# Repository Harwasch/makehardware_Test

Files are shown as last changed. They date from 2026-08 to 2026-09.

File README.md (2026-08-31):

# Ulysses LARS Charger

A 3 kW magnetic-resonant wireless charger that moves power from a surface
vessel's dock to a 48 V pack in an underwater vehicle, across a gap no
connector ever crosses.

Built with the [MakeHardware](https://github.com/Harwasch/MakeHardware) workflow.
This is **revision 2**; revision 1 is documented in
[`docs/design/v1-baseline.md`](docs/design/v1-baseline.md) and its source
material is preserved under `docs/reference/source/`.

<!-- PLAN:BEGIN -->
<!-- generated by plan_render.py — edit plan.yaml, not this block -->

Project plan

**0/28 chunks complete** · 16 sessions on the critical path · [editable version](docs/plan.drawio)

<!-- PLAN:END -->

## Where things stand

The four agreement stages — vision, plan, requirements, architecture — are
done. No design artefact exists yet, so `req-trace --gate` correctly reports
0% verified.

**There is no laboratory access.** Every number in this repository is an
analysis or simulation result, and the documents say so where it matters. Bench
verification is held as chunk `T2`, blocked, rather than deleted.

| Document | What it is |
|---|---|
| [`docs/design/vision.md`](docs/design/vision.md) | What we are building and the one decision it turns on |
| [`docs/design/v1-baseline.md`](docs/design/v1-baseline.md) | Revision 1 reviewed against its own datasheets — eleven findings, three blocking |
| [`docs/design/coil-model.md`](docs/design/coil-model.md) | Coil inductance, coupling and Q predicted from first principles |
| [`docs/design/in-band-comms.md`](docs/design/in-band-comms.md) | Data over the power coils, and why the tank bandwidth is the constraint |
| [`docs/design/environment.md`](docs/design/environment.md) | The marine ambient envelope and the 45 °C thermal budget it leaves |
| [`docs/design/adr-0002-tx-power-stage.md`](docs/design/adr-0002-tx-power-stage.md) | TX switch selection, and the two consequences worth knowing |
| [`docs/design/friction-log.md`](docs/design/friction-log.md) | What cost time, and which MakeHardware file should change |

## Reproducing the analysis

Every load-bearing number comes from a script, not a paragraph:

```bash
/opt/hw-py/bin/python sim/link-budget/link_budget.py     # resonant link matching, k*Q, loss budget
/opt/hw-py/bin/python sim/link-budget/comms_budget.py    # in-band data rate against tank bandwidth
/opt/hw-py/bin/python sim/link-budget/charge_policy.py   # C-rate policy and what it implies about the pack
cd sim/coil
/opt/hw-py/bin/python coil_model.py       # inductance, two methods, cross-checked
/opt/hw-py/bin/python coil_coupling.py    # coupling across the misalignment envelope
/opt/hw-py/bin/python coil_resistance.py  # AC resistance and quality factor
```

## The gates

```bash
hw-doctor                 # what the toolchain can actually do right now
/hw-status                # plan progress, what is ready to start, requirements coverage
plan-render --check       # cycles, dangling deps, done-on-unfinished
block-diagram --check     # architecture gate; exit 1 on an over-budget rail
./scripts/arch_diagram.py         # architecture sheets + power-budget.csv; fails
                                  #   on a wire over a box or a sheet too wide
./scripts/vision_md.py            # render concepts/ -> vision-gallery.md, HTML flattened
./scripts/md_flatten.py --check docs/review/*.md docs/design/*.md
req-trace --gate          # traceability gate; exit 1 while gaps remain
```

`req-trace --gate` exits 1 today and should. Do not make it pass by marking a
requirement `Verified` without evidence at the corners.

## Environment

This repo needs a Claude Code cloud environment built from
[MakeHardware's `env/`](https://github.com/Harwasch/MakeHardware/tree/HEAD/env) —
network access **Full**, the environment variables file, and the setup script.
Run `hw-doctor` first if anything behaves unexpectedly; the friction log records
two setup defects worth fixing before the next session.

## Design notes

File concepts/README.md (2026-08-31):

# concepts/

build123d models for the vision stage. Every dimension here is one the model
actually holds — these are geometry renders, not artistic impressions, so a
concept cannot show something unbuildable.

```bash
vision-md            # renders concepts/*.py and writes docs/design/vision-gallery.md
```

Run `vision-md`, not `vision-board` directly: it points the generated gallery at
`vision-gallery.md` so it stops overwriting the hand-written `vision.md`, and it
flattens the raw `<details>` blocks `vision-board` emits, which `review-artifact`
escapes into visible tags on the published review page.

| File | Concept |
|---|---|
| `_common.py` | shared geometry — coil pad, housing, enclosure, finned sink, dowel |
| `test_packaging.py` | the bench rig: pads on pins, gap set by shims |

**Scope is the electronics plus this one rig** (`VIS-013`). Integration — the
deck fixture, the vehicle mounting, the handling — is the mechanical team's, so
the rig is test equipment and not a fixture prototype. It is not marine, not
recoverable and not handled.

Two earlier generations of concept are withdrawn and deleted rather than kept as
dead files, because a stale concept is read as a live proposal:

* `dock_belly.py`, `dock_flank.py`, `dock_saddle.py` — docking arrangements.
  Settled at gate 1: belly dock, no actuator, charge on deck.
* `locate_cone_vee.py`, `locate_tapered_rails.py`, `locate_nest.py` — locating
  schemes. Withdrawn 2026-08-31 with the fixture; pins were taken from among
  them as the interface (`VIS-005`).

The coil pad is real — 102 × 203 mm at a 16 mm stack, from
`sim/coil/coil_rect.py`. The finned sink is sized against `MEC-009` and reports
its own area rather than asserting it; `sink_area_cm2()` is the number quoted.

Mass figures in the gallery are quoted at 1.4 g/cm³, which is `vision-board`'s
fixed assumption and wrong for an aluminium rig — `MATERIAL` sets the render
colour only. Multiply by 1.93 for aluminium, and remember the enclosures are
drawn as solid blocks.

No image backend is configured in this environment (`imagegen --list` reports no
keys), so styled or contextual imagery is not available. If the vision board
should look like a product rather than shaded CAD, that needs `FAL_KEY`,
`BFL_API_KEY` or `OPENAI_API_KEY` set in the environment.

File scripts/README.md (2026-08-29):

# scripts/

Vendored copies of the MakeHardware gate scripts, so the gates run in CI without
the plugin being installed.

| Script | What it does |
|---|---|
| `req_trace.py` | Traceability and coverage gate over `requirements/`. Exits 1 while gaps remain. |

These are **copies**, not the source of truth — the originals live in the
MakeHardware plugin and are what a local session runs via `req-trace`. If the
plugin's version changes, re-copy. The reason for vendoring rather than
installing the plugin in CI is that the plugin pulls a large toolchain (KiCad,
CalculiX, gmsh) that a documentation build has no use for.

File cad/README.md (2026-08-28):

# CAD

build123d models. Each file defines the geometry as code so a changed number is
a re-render, not a redraw.

Export STEP for the KiCad 3D view and STL for meshing. Link each model back to
the requirement it realises with a `File` relation in `requirements/`.

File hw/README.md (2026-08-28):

# Electrical design

| File | What it is |
|---|---|
| `block-diagram.yaml` | the architecture spec — **the only file here you hand-edit** |
| `block-diagram.drawio` | generated; open in draw.io to rearrange, positions are kept |
| `*.kicad_sch`, `*.kicad_pcb` | KiCad project — change these **only** through Konnect MCP tools |

The block diagram is settled before schematic capture. See the
`hw-block-diagram` skill; run `block-diagram --check` before calling the
architecture agreed.

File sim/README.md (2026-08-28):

# Simulation

SPICE decks and their results. A simulation only closes a requirement if it is
reproducible, so commit the deck alongside the numbers it produced.

Cross-check against closed form wherever one exists, and read the
`observations` field — ngspice prints `singular matrix` and then writes
plausible numbers anyway.

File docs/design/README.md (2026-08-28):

# Design documentation

How and why this system was built, written as the work happens.

* `adr-NNNN-<slug>.md` — decision records. One per decision that constrains
  anything downstream.
* `architecture.md` — the block-level picture and how the pieces divide.
* `interfaces.md` — board outline, connector pinouts, mounting, anything two
  disciplines have to agree on.
* `verification-report.md` — the output of the verification stage.
* `friction-log.md` — three-line entries written during the work, whenever a
  correction or an avoidable loop happens, each naming the MakeHardware file
  that should change. See the `hw-retro` skill.
* `retro.md` — the synthesis, written by `/hw-retro` at a milestone.

An ADR has: Status, Context, Decision, Consequences, Alternatives considered.
Write the Consequences honestly, the bad ones included — that section is what a
future session reads when the number has to move.

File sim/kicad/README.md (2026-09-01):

# sim/kicad — the DAB schematic, and how to run it

`dab-sim` is a full dual active bridge — eight switches, their body diodes, the
planar transformer and the customer-supplied 56 µH — drawn as a schematic and
simulated by ngspice. Everything in the power path is a drawn wire, so you can
trace it by eye; only the four gate nets `G1`–`G4` are labels.

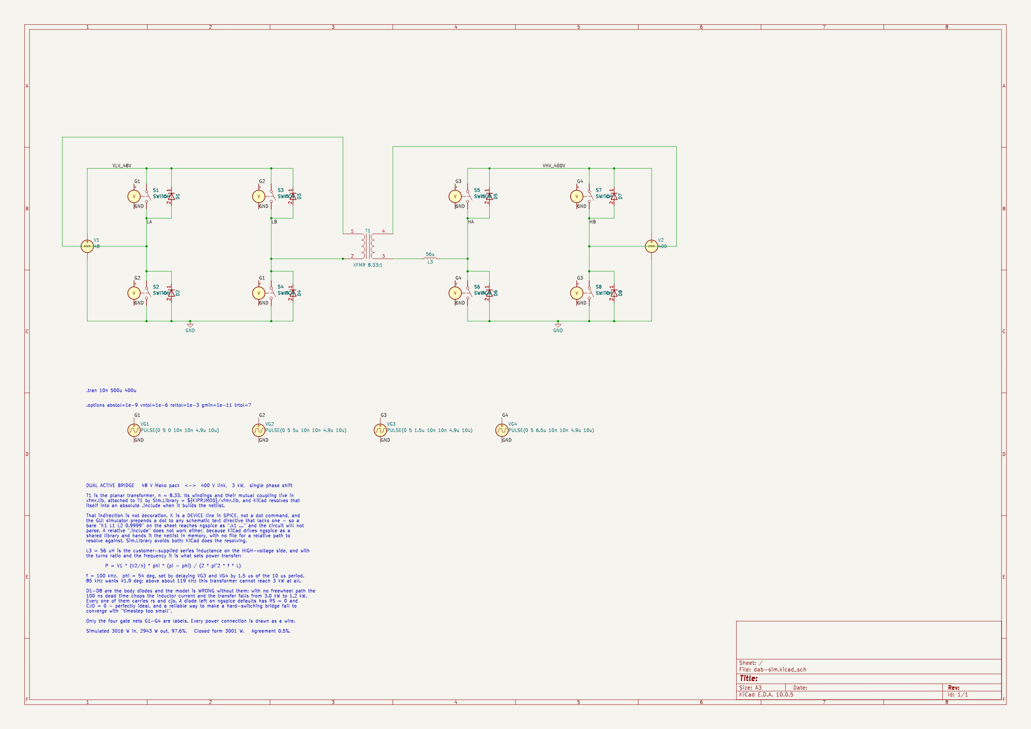
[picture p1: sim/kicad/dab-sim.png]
schematic


---

## Running it on your machine

### 1. What you need

**KiCad 8 or newer.** Built and verified here on **10.0.5**. The simulator is
ngspice, embedded in KiCad:

| Platform | ngspice |
|---|---|
| Windows | bundled with the KiCad installer — nothing to do |
| macOS | bundled with the KiCad `.dmg` — nothing to do |
| Linux | usually pulled in with the `kicad` package via `libngspice0`. If Simulator is greyed out, install `libngspice0` (Debian/Ubuntu) or `libngspice` (Fedora/Arch) and restart KiCad |

Nothing else. No SPICE models to fetch, no libraries to register — every symbol
is a stock KiCad one (`Simulation_SPICE`, `Device`, `power`) and the schematic
carries its own copy of each.

### 2. Open and run

```
git clone <this repo>
kicad sim/kicad/dab-sim.kicad_pro          # or File > Open Project
```

**The Simulator is in the Schematic Editor, not the Project Manager.** Open the
schematic first — double-click `dab-sim.kicad_sch` in the project tree, or press
the Schematic Editor button — and the **Inspect** menu appears. Simulator is
under it.

**Run will ask you for the simulation settings the first time. Give it:**

| Field | Value |
|---|---|
| Analysis | Transient |
| Time step | `10n` |
| Final time | `500u` |
| Time to start saving data | `400u` |

or, if the dialog offers a custom/direct command box, paste
`.tran 10n 500u 400u` into it. KiCad stores the command in the schematic, so it
only asks once.

**Why it asks, when the directive is right there on the sheet.** KiCad treats a
text item as *the simulation command* only when its **first line** starts with a
`.`. The directive block on this sheet reads

```
K1 L1 L2 0.9999          <- first line, does not start with a dot
.tran 10n 500u 400u
```

Both lines are exported into the netlist correctly — the coupling and the
analysis are genuinely there, which is why `run.sh` works — but the GUI does not
recognise the block as a simulation command, so it prompts.

### 3. The transformer coupling — already handled, but know why

Mutual coupling in SPICE is the `K` element, and **`K` is a device line, not a dot
command**. KiCad's GUI simulator prepends a `.` to any schematic text directive
that does not already start with one, so a bare `K1 L1 L2 0.9999` on the sheet
arrives at ngspice as `.k1 l1 l2 0.9999` and the circuit will not parse. Moving
it into a file and using a relative `.include` fails too: KiCad drives ngspice as
a **shared library** and hands it the netlist in memory, so there is no netlist
file for a relative path to resolve against.

Both are avoided here. The windings and their coupling live in `xfmr.lib` as a
subcircuit, attached to `T1` by

```
Sim.Library = ${KIPRJMOD}/xfmr.lib
Sim.Device  = SUBCKT
Sim.Name    = XFMR
```

**KiCad resolves that path itself** and writes an absolute, quoted `.include`
into the netlist. Absolute, so the shared library finds it; quoted, so a path
through a folder like `Wireless Charging Sim` is fine; and `${KIPRJMOD}` keeps it
portable, because the variable is resolved at netlist time on whatever machine
runs it. Nothing for you to edit.

### 4. Probing

With the Simulator window open, click a wire in the schematic to add it to the
plot; click a component pin to add its current. The nets worth probing are
already named, so they come up with sensible titles rather than `Net-_D1-A_`:

| Probe this | To see |
|---|---|
| `LA` and `LB` | the low-voltage bridge output — a 48 V square wave |
| `HA` and `HB` | the high-voltage bridge output — 400 V, phase shifted |
| current in **L3** | the tank current in your 56 µH. This is the waveform that matters: trapezoidal, and its slope is the voltage across the inductance |
| current in **V1** | input current from the 48 V pack, about 62.6 A average |
| current in **V2** | output current into the 400 V link, about 7.35 A average |
| `G1`–`G4` | the four gate drives, so you can see the phase shift |

For power rather than current, use the plot's **Add signal → expression** and
enter `v(/LA)*i(L1)` or similar.

### 5. Moving the operating point

Phase shift is the control input, and it is set by **when the high-voltage
bridge switches relative to the low-voltage one** — the delay field in `VG3`
and `VG4`. At 100 kHz the period is 10 µs, so 1 µs of delay is 36°.

| Want | Set VG3 delay | and VG4 delay |
|---|---|---|
| 54° — 3.0 kW, the shipped setting | `1.5u` | `6.5u` |
| 30° — less power, lowest current | `0.833u` | `5.833u` |
| 90° — maximum power, worst current | `2.5u` | `7.5u` |

Keep VG4 exactly 5 µs after VG3: they are the two halves of the same bridge.

To change frequency, every `10u` period and `4.9u` width in all four gate
sources has to move together, and the delays with them. **Above about 119 kHz
this transformer cannot reach 3 kW at any phase shift** — 56 µH is the limit.

### 6. Headless

Same schematic, same ngspice, no clicking:

```bash
./sim/kicad/run.sh              # measurements and a waveform plot
./sim/kicad/run.sh --no-plot    # measurements only, no matplotlib needed
```

It exports the netlist from the schematic with `kicad-cli`, swaps the `.tran`
for a `.control` block that also measures, runs it, and prints:

```
  input from the 48 V pack     3015.5 W   (62.82 A)
  output into the 400 V link   2942.9 W   (7.357 A)
  efficiency                     97.6 %
  tank current, HV side          9.53 A rms   10.34 A peak

  closed form for these values: 3001 W.  Deviation 0.5%.
```

Those are the numbers to expect from a clean run. If yours differ, something
changed. `PYTHON=/path/to/python ./run.sh` if the default interpreter has no
matplotlib.

---

## What the circuit is

`L1` / `L2` are the planar transformer, n = 8.33 so `L2 = L1 · n²`, coupled by
`K1` at 0.9999 — which makes `L3` the only leakage, deliberately, because `L3`
**is** the customer's 56 µH series inductance on the high-voltage side. That
inductance, the turns ratio and the frequency are what set power transfer:

```
P = V1 · (V2/n) · φ · (π − φ) / (2 · π² · f · L)
```

`D1`–`D8` are the body diodes, and **the model is wrong without them**: with no
freewheel path the 100 ns dead time chops the inductor current and the transfer
falls from 3.0 kW to 1.2 kW. That is measured, not asserted.

## Things that will bite you if you edit this sheet

**`Sim.*` properties must be on the symbol instance, not just the library.** A
symbol placed programmatically carries only Reference/Value/Footprint/Datasheet,
and the netlist then exports `S1 __S1` — no nodes, no model, and a run that
produces zero data rows. Every simulated part here carries `Sim.Device`,
`Sim.Pins` and `Sim.Params` as instance properties for that reason.

**Do not draw a rail straight across a row of switches.** The `SWITCH` symbol
puts its control pins at the same heights as its power pins, one grid column to
the left, so a horizontal rail through a switch row passes through every `C+`
pin and shorts the supply to the gate net. ngspice says `singular matrix: check
node vg2#branch` and returns nothing. The rails here run above and below the
switch rows with short stubs down to each pin — that is why the top rail sits at
y = 68.58 rather than on the pin row.

**Every diode carries `rs` and `cjo`, and that is not cosmetic.** A diode left
on ngspice's defaults has `RS = 0` and `CJO = 0` — a perfectly ideal switch with
no series resistance and no junction capacitance. In a hard-switching bridge
that is a reliable way to get `Timestep too small ... trouble with d4-instance`
and an aborted run. If you add a device to this sheet, give it real parameters.
The `.options` line beside the `.tran` loosens `abstol` from its 1 pA default,
which is meaningless in a circuit carrying 60 A.

**One ERC error is expected.** `power_pin_not_driven` on the GND symbols: KiCad
wants a `PWR_FLAG`, which matters for a board and not for a simulation. The
other ERC warnings you may see are library-table complaints that only appear if
`Simulation_SPICE`, `Device` or `power` are not in your global library table —
on a normal KiCad install they are.

## What this deck does not do

No switching loss, no ZVS, no parasitics, no thermal. The switches are ideal
with a 5 mΩ on-resistance and the diodes are generic. That is chunk `S2`, and it
needs real device models — the BSC190N15NS3 and IPB60R120C7 datasheets are still
listed as blocked in `docs/reference/manifest.yaml`.

The companion hand-written decks in `sim/link` and `sim/dab` cover the resonant
link and the phase-shift sweep. Findings from all of them are in
[`docs/design/sim-findings.md`](../../docs/design/sim-findings.md).

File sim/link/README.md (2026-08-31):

# sim/link, sim/dab

Two ngspice decks. Both are run by a Python driver that sweeps them and
cross-checks every point against closed form, because a simulator that agrees
with arithmetic is evidence and one that does not is a broken deck.

```bash
./sim/link/run_link.py     # resonant link  -> docs/design/sim-link.md
./sim/dab/run_dab.py       # DAB transformer -> docs/design/sim-dab.md
```

Read [`docs/design/sim-findings.md`](../../docs/design/sim-findings.md) for what
the numbers mean. The generated tables are numbers only.

**`link.cir`** is a faithful model of the white paper's resonant link: measured
coil values from page 6, bulk capacitance from page 5, 400 V bus, 85 kHz. Only
the compensation capacitance is computed, because the paper does not give it.

**`dab.cir`** is not a model of the white paper's DAB and cannot be. Page 8
names every semiconductor and none of the three parameters that set DAB power
transfer — turns ratio, leakage inductance, switching frequency. The deck runs
the inverse and solves for the leakage inductance 3 kW needs.

Neither deck carries switching loss, ZVS, dead time or parasitics; both use
ideal square-wave sources. That is chunk `S2`, and it is blocked on datasheets
that are not yet fetched — see `docs/reference/manifest.yaml`.

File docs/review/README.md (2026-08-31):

# Human review

An artefact the human has not seen is not a deliverable.

This directory is where agreement is recorded. Each review is a page the
human can open in a browser on github.com — because the agent works in a
cloud VM and that is the only surface the human actually has — plus a line in
`reviews.yaml` saying what they decided and what the artefacts looked like
when they decided it.

```
reviews.yaml       the sign-off ledger, with a digest per agreed artefact
<id>.md            one review packet per milestone or design stage
```

## The four milestones, at a minimum

| id | The artefact that renders on GitHub |
|---|---|
| `vision` | `docs/design/vision.md` and the renders beside it |
| `plan` | `docs/plan.md` (scope) and `docs/plan.svg` (dependency Gantt) |
| `requirements` | `docs/design/requirements-map.svg` |
| `arch` | `docs/design/arch-system.svg`, `arch-link.svg`, `arch-dab.svg`, `block-diagram.svg` |

Then one per large design stage — schematic, layout, enclosure, each
simulation campaign.

## The loop

```bash
review-gate open vision --title "..." --summary "..." \
    --artifact docs/design/vision.md --artifact docs/design/vision/ \
    --reference concepts/ \
    --question "Which concept, and why?"

#  ... ask the human directly with the printed github.com link, and wait ...

review-gate sign vision --approve --by <name> --note "<what they said>"
review-gate list                 # where every review stands
review-gate check --gate         # exit 1 while any milestone is open or stale
```

`--artifact` is what they are agreeing to: change one after sign-off and the
review goes **stale**, which fails the gate. `--reference` is a link to a
source file that legitimately churns — `plan.yaml`, a live `.kicad_sch` —
so the review does not break on every ordinary edit.

A chunk in `plan.yaml` that names a `review:` cannot be marked `done` until
that review is signed off. `plan-render --check` refuses it.

Full detail: the `hw-review` skill, and `hw-review/references/exports.md` for
how to turn a schematic, a board or a CAD model into something a browser can
open.

## Why the architecture milestone is `arch`, not `architecture`

`review-artifact`'s standard architecture phase is hardcoded to one figure,
`docs/design/block-diagram.svg`, and does not read the review's artefact list —
so a reviewer whose only access is the published page saw one diagram where
four were sent. It is replaced by a configured phase in
[`artifact.yaml`](artifact.yaml), which must use a different id because `hide`
suppresses a configured phase of the same id as well as the standard one. The
review binds to a phase by id, so the review is `arch` too, which keeps the
questions on the same tab as the drawings they are about.

`review-gate list` reports `architecture` as "never requested" for that reason.
That is expected, not a gap.

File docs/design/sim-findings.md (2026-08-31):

# What the simulations say

Two decks, both on ngspice-42, both cross-checked against closed form on every
point. Numbers live in the generated tables — [`sim-link.md`](sim-link.md) and
[`sim-dab.md`](sim-dab.md); this is what they mean.

Run them with `./sim/link/run_link.py` and `./sim/dab/run_dab.py`.

## What could be simulated, and what could not

The white paper supports a **faithful** simulation of the resonant link. It
gives measured coil values on page 6 — 12 µH, 0.8 Ω, Q of 12 — a 400 V bus, an
80–120 kHz band with 85 kHz nominal, and 11 µF of rectifier bulk capacitance on
page 5. Only the compensation capacitance is missing, and that follows from
resonance.

It does **not** support a simulation of the DAB. Page 8 names every
semiconductor — IPB60R120, BSC190N, UCC27741, ISO7740, ISO224, UCC1414,
UCC33420, TPSM560 — and none of the three parameters that set a DAB's power
transfer: transformer turns ratio, leakage inductance, switching frequency. A
deck built on assumed values would simulate our assumptions, not the design. So
`sim/dab/dab.cir` runs the inverse instead and solves for the transformer the
converter needs.

## F14 — the v1 coils cannot transfer 3 kW, by a factor of 6.75 in k

This is arithmetic before it is simulation. For series-series compensation
between two 400 V bridges,

    P = V1 * V2 / (omega * M)

so 3.0 kW at 85 kHz from a 400 V square wave (360 V rms fundamental) needs
**M = 80.9 µH**. Mutual inductance cannot exceed self-inductance, and the white
paper's coils are **12 µH**. Reaching 3 kW would need k = 6.75, where k ≤ 1 by
definition. The coils are roughly an order of magnitude too small.

The simulation shows what that looks like in practice. Driven at resonance at
400 V, the v1 tank draws **403 A rms** and puts **4.07 kV** across the
compensation capacitor. The LMG2610 the white paper selects is rated 6.4 A.
Coil dissipation at that current is 403² × 0.8 ≈ **130 kW** in a pad that has
to shed its heat by conduction alone.

The v1 link is therefore not a design that underperforms; it is one that cannot
be operated at its stated bus voltage at resonance at all. Which is consistent
with what the white paper reports from the bench: a resonance tracker that
hunts, and a system characterised at far lower power.

**Held fixed:** 85 kHz drive, 400 V bus, series-series compensation, the coil
as built. **Not varied:** operating frequency far off resonance, a lower bus
voltage, parallel compensation. Any of those makes the v1 hardware *do*
something — none of them makes it deliver 3 kW, because M is the binding limit
and none of them changes M.

## F15 — the white paper's Q of 12 does not hold at the stated frequency

Q = ωL/R with the paper's own L and R gives **8.0 at 85 kHz**, not 12. Q reaches
12 at about 127 kHz, above the top of the 80–120 kHz band the paper specifies.
Nothing downstream depends on this, but a Q quoted without its frequency is how
a coupling budget goes wrong, and `MEC-001` is written as k·Q for that reason.

## F16 — the corrected coil works, and puts 471–622 V on the rectifier

The ADR-0001 design point — 24 turns, 0.25 mm trace, 4 oz, 16 transposed
layers, from `sim/coil/coil_rect.py`, not from memory — gives L = 220 µH,
R_ac = 0.673 Ω and k of 0.433 to 0.572 across the `SYS-006` envelope. Simulated,
it moves 2.1–2.8 kW at **4–8 A** of tank current: three orders of magnitude off
the v1 currents, and inside every device rating.

But the operating point is not where the architecture assumes. With a passive
rectifier, output voltage is set by the load, and delivering 3 kW puts the
rectifier at **471 V at the worst corner, 566 V nominal and 622 V at minimum
gap** — not the 400 V of the `HVDC` rail in `hw/block-diagram.yaml`. Two
consequences, and both are open:

* The rail is misspecified. `HVDC` is 400 V in the block diagram and the real
  figure is roughly 470–620 V, which changes the device voltage class on the
  vehicle DAB's high-voltage bridge.
* It **varies by 32% across the docking envelope** at constant power. The
  downstream DAB has to absorb that, which is a control requirement nobody has
  written yet.

An actively rectified receiver would decouple power from output voltage and
remove both. That is an architecture decision, not a simulation result, and it
belongs to the human.

## F17 — the vehicle DAB's loss budget does not close, and ELE-003's rationale was wrong

Solving for the transformer at 3 kW, 48 V to 400 V:

| φ | L_lk referred to LV | referred to HV | tank rms |
|---:|---:|---:|---:|
| 30° | 0.53 µH | 37 µH | 70.7 A |
| 90° | 0.96 µH | 67 µH | 102.3 A |

at 100 kHz; at 150 kHz the inductances scale by 2/3 and the currents do not
move. Small phase shift is clearly right — same power, 30% less current — and
0.53 µH referred to the low-voltage side is the number the planar transformer
should be specified to.

The conduction loss that follows is the problem. Each switch position conducts
for half the cycle, so a device carries I_rms/(√2·N) with N in parallel, and the
whole low-voltage bridge costs 2·I_rms²·R_ds/N:

* **two devices per branch**, as the white paper specifies — **152 W** at the
  best phase shift
* **four devices per branch**, as `ELE-003` specifies — **76 W**

`ELE-003` budgets **100 W for the entire vehicle-side converter**, rectified DC
to pack terminals. Four per branch spends 76% of that on low-voltage conduction
alone, before the high-voltage bridge, the transformer, or any switching loss.
Two per branch exceeds the whole budget by 52%.

**`ELE-003`'s rationale was wrong and has been corrected.** It claimed 74 W for
two devices and 37 W for four; both were understated about twofold because the
half-cycle factor was dropped. The conclusion it drove — four devices per branch
rather than two — survives and is strengthened. The budget it asserts does not.

`R_ds(on)` here is the 19 mΩ family figure for BSC190N15NS3 scaled 1.6× for
temperature, and it is **not confirmed against a fetched datasheet**. It is
recorded as blocked in `docs/reference/manifest.yaml`. The 100 W budget is the
requirement's, so the gap is real either way, but its size moves with this
number and it should be confirmed before `ELE-003` is re-budgeted.

## What these decks do not cover

Deliberately, and they should not be read as if they did:

* **No switching loss, no ZVS, no dead time.** Both decks use ideal square-wave
  sources. That is the right reduction for a power-transfer question and the
  wrong one for a thermal answer. Chunk `S2` needs real device models, and
  those need datasheets that are not yet fetched.
* **No EMC, no parasitics.** The white paper is explicit that GaN slew rate and
  loop inductance are the hard part of the TX layout; nothing here models that.
* **The rectifier is a generic fast diode.** The paper names MURSDA860 but gives
  no ratings, and a 400 V — let alone 620 V — rectifier is a voltage-class
  question. Recorded as blocked in the manifest.
* **The DAB deck is a power-transfer core**, two square waves across the
  leakage inductance. It says nothing about the magnetising current, the
  transformer's loss, or bridge behaviour at light load.

## F18 — the M = 80.9 µH target assumed an ACTIVE receiver, and the deck used a passive one

Raised by the customer, and they were right to ask. To be clear first: **M is
about the wireless TX-to-RX link, not the DAB.** The DAB has its own series
inductance, and it is a different number in a different place.

The muddle is real, though, and it is mine. Two formulas describe an SS-compensated
link and they are not interchangeable:

* both ends actively switched — `P = V1 * V2 / (omega * M)`. This is what gives
  M = 80.9 uH for 3 kW at 85 kHz between two 400 V bridges, and it is what
  ``MEC-002`` was written from.
* a passive diode rectifier on the receiver — `P = V1^2 * R_ac / (omega * M)^2`,
  where the output voltage is set by the load, not by a bridge.

`sim/link/link.cir` models a **passive** rectifier, because that is what
``U10`` is in the block diagram. So the 80.9 uH figure and the simulation
describe two different receivers, and F16's 471-622 V output is exactly the
symptom of that mismatch.

This sharpens the F16 decision rather than replacing it. **Active rectification
restores M = 80.9 uH as the design target AND regulates the output back to
400 V — it fixes both problems at once.** A passive rectifier means ``MEC-002``
has to be rewritten, because M stops being the governing quantity.

## F19 — the coil is designed for the wrong M, and 24 turns is 20

Following F18 through to the active-rectifier case exposes a second-order error
in ``ADR-0001``. Power transfer is INVERSELY proportional to omega times M, so
too much coupling limits power just as surely as too little:

| turns | L | M | k·Q | P max at 400 V, 85 kHz |
|---:|---:|---:|---:|---:|
| 24 (ADR-0001) | 220 µH | 114.6 µH | 90.9 | **2.12 kW** |
| 22 | 192 µH | 97.9 µH | 84.2 | 2.48 kW |
| **20** | **166 µH** | **82.2 µH** | **77.3** | **2.95 kW** |
| 18 | 140 µH | 67.7 µH | 70.3 | 3.59 kW |

``ADR-0001`` picked 24 turns by maximising k·Q, which is the EFFICIENCY figure,
and never checked M against the POWER requirement. At 24 turns the link tops out
at 2.12 kW — it cannot reach 3 kW at 400 V however well it is driven.

**20 turns gives M = 82.2 µH against the 80.9 µH ``MEC-002`` asks for, reaches
2.95 kW, and still carries k·Q of 77.3 against the 49 ``MEC-001`` requires.**
The efficiency margin was never the binding constraint; it just looked like it
because it was the only thing being optimised.

``ADR-0001`` and ``MEC-002`` both need revising to 20 turns, and that is M2's
work. It does not change the coil technology decision — a transposed
multi-layer etched PCB coil still passes — only the turn count.

## F20 — the 56 µH lands inside the range the DAB deck solved for

The customer supplied it: there is a **56 µH inductor in series with the DAB's
PCB-coil transformer**. `sim/dab/run_dab.py` had solved for 37-67 µH referred to
the high-voltage side, so the real part sits squarely inside the predicted band,
which is a useful check on the deck.

It must be the high-voltage side: referred to the low-voltage side, 56 µH would
cap the converter at 51 W. Referred properly it is 0.806 µH, and it pins the
operating point that was previously open:

| f | phase shift for 3.0 kW |
|---:|---:|
| 85 kHz | 41.9° |
| 100 kHz | 54.0° |
| 150 kHz | cannot reach 3 kW at any phase shift |

**The transformer as built cannot deliver 3 kW above about 119 kHz.** That is a
hard constraint on the switching frequency that nothing in the white paper
states, and it should go into the electrical requirements.

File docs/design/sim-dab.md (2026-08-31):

# Dual active bridge — solving for the transformer

Generated by `sim/dab/run_dab.py` from `sim/dab/dab.cir` on ngspice-42. Do not edit by hand.

**This is not a simulation of the white paper's DAB.** The white paper names every semiconductor in the converter (page 8) and none of the three parameters that set its power transfer — transformer turns ratio, leakage inductance, switching frequency. What follows runs the inverse: for each candidate phase shift, the leakage inductance that delivers 3 kW, simulated, with the current the bridges would carry.

48 V to 400 V, turns ratio 8.33:1, 3.0 kW, 8 mΩ loop resistance.

| f kHz | φ ° | L_lk µH (LV) | L_lk µH (HV) | P sim W | error | I rms A | I pk A | W/FET (2 per branch) | LV bridge W | W/FET (4 per branch) | LV bridge W |
|---:|---:|---:|---:|---:|---:|---:|---:|---:|---:|---:|---:|
| 100 | 30 | 0.533 | 37.0 | 3019 | 0.6% | 70.7 | 77.6 | 19.0 | 152 | 4.7 | 76 |
| 100 | 45 | 0.720 | 50.0 | 3025 | 0.8% | 76.1 | 87.0 | 22.0 | 176 | 5.5 | 88 |
| 100 | 60 | 0.853 | 59.3 | 3031 | 1.0% | 82.8 | 99.4 | 26.0 | 208 | 6.5 | 104 |
| 100 | 90 | 0.960 | 66.7 | 3049 | 1.6% | 102.3 | 134.2 | 39.8 | 318 | 9.9 | 159 |
| 150 | 30 | 0.356 | 24.7 | 3018 | 0.6% | 70.7 | 76.9 | 19.0 | 152 | 4.7 | 76 |
| 150 | 45 | 0.480 | 33.3 | 3022 | 0.7% | 76.1 | 84.9 | 22.0 | 176 | 5.5 | 88 |
| 150 | 60 | 0.569 | 39.5 | 3027 | 0.9% | 82.7 | 95.6 | 26.0 | 208 | 6.5 | 104 |
| 150 | 90 | 0.640 | 44.4 | 3043 | 1.4% | 102.1 | 127.8 | 39.6 | 317 | 9.9 | 158 |

## Simulator observations

None. No singular-matrix or convergence warnings on any run.

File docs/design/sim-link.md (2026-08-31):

# Resonant link simulation

Generated by `sim/link/run_link.py` from `sim/link/link.cir` on ngspice-42. Do not edit by hand.

Drive 400 V square wave at 85 kHz, fundamental 360 V rms. Series-series compensation, each side tuned to resonance at the drive frequency. Full-bridge rectifier into a bulk capacitor and a resistive load.

| Design | k | R_load Ω | ωM Ω | I_tx sim A | I_tx closed form A | V_out V | P sim W | P closed form W | error |
|---|---:|---:|---:|---:|---:|---:|---:|---:|---:|
| v1 white paper | 0.20 | 53.3 | 1.3 | 428.4 | 429.7 | 626 | 7355 | 7023 | 4.7% |
| v1 white paper | 0.30 | 53.3 | 1.9 | 403.4 | 406.7 | 887 | 14775 | 14150 | 4.4% |
| v1 white paper | 0.52 | 53.3 | 3.3 | 314.8 | 340.7 | 1196 | 26845 | 29837 | 10.0% |
| v1 white paper | 0.70 | 53.3 | 4.5 | 232.8 | 284.5 | 1196 | 26850 | 37704 | 28.8% |
| v2 ADR-0001 | 0.52 | 53.3 | 61.2 | 4.3 | 4.1 | 283 | 1502 | 1474 | 1.9% |
| v2 ADR-0001 | 0.52 | 106.8 | 61.2 | 7.9 | 8.2 | 532 | 2646 | 2908 | 9.0% |
| v2 ADR-0001 | 0.43 | 53.3 | 50.9 | 6.1 | 5.9 | 337 | 2127 | 2111 | 0.8% |
| v2 ADR-0001 | 0.43 | 73.9 | 50.9 | 8.3 | 8.2 | 459 | 2849 | 2902 | 1.9% |
| v2 ADR-0001 | 0.57 | 129.0 | 67.3 | 7.6 | 8.2 | 562 | 2452 | 2903 | 15.5% |

Peak voltage on the compensation capacitor, which is what the part has to be rated for:

| Design | k | V_tank peak V | Output ripple V pp |
|---|---:|---:|---:|
| v1 white paper | 0.20 | 4288 | 4.44 |
| v1 white paper | 0.30 | 4066 | 7.34 |
| v1 white paper | 0.52 | 3272 | 5.63 |
| v1 white paper | 0.70 | 2548 | 5.71 |
| v2 ADR-0001 | 0.52 | 1124 | 1.40 |
| v2 ADR-0001 | 0.52 | 1730 | 16.59 |
| v2 ADR-0001 | 0.43 | 1422 | 1.69 |
| v2 ADR-0001 | 0.43 | 1781 | 5.91 |
| v2 ADR-0001 | 0.57 | 1674 | 24.32 |

## Simulator observations

None. No singular-matrix or convergence warnings on any run.

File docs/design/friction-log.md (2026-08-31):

# Friction log

Three lines per entry, written as it happens. One of them names the
MakeHardware file that should change. See the `hw-retro` skill.

---

**The power budget adds child-rail current to its parent without referring it
through the voltage ratio.** `block_diagram.py` has a 400 V rail feeding a 48 V
rail through an isolated DAB; the roll-up added 67 A of 48 V load straight onto
the 400 V rail and declared it 8x over budget, which stopped the gate being
usable until the tree was restructured.
The docstring in `budget()` says loads are "referred through their regulators",
but the code does `rows[parent]["max"] += rows[rid]["max"]` with no voltage
term, so the promise and the behaviour disagree.
**Fix `scripts/block_diagram.py`, `budget()`:** multiply by
`child_voltage / parent_voltage` when rolling up, or drop the claim from the
docstring and say plainly that the check is conservative. As written, any
project with a large step-down gets an answer that is wrong by the step ratio —
here 8.3x — and the natural workaround (declaring rails independent) only
happens to be correct because both converters are galvanically isolated.

---

**A single package timing out took the entire Python toolchain down, silently.**
`phase_python()` in `env/setup.sh` installs eleven packages in one `uv pip
install`; `pandas` metadata timed out, the whole phase returned 1, and the venv
was left empty. `hw-doctor` then reported strictdoc, pyyaml, build123d,
build123d-mcp and ltspice-mcp all FAIL — five separate-looking failures from one
network hiccup, with nothing to indicate they shared a cause.
Reinstalling in four smaller groups worked first time on the same network.
**Fix `env/setup.sh`, `phase_python()`:** split the install into an essential
group (strictdoc, pyyaml — the requirements and planning gates) and optional
groups, so a transient failure on a plotting dependency cannot take out the
requirements toolchain. `pandas` in particular is not imported by any script in
`scripts/`.

---

**`build123d-mcp` and `ltspice-mcp` cannot coexist in one venv.** `build123d-mcp
0.3.83` requires `mcp>=2,<3`; `ltspice-mcp` pins `mcp[cli]<2.0,>=1.27.0`.
Whichever resolves last wins and the other dies at import, so `hw-doctor` shows
one of the two MCP servers failing no matter what — which reads as a broken
install rather than a dependency conflict.
Resolved here by giving `build123d-mcp` its own venv at `/opt/hw-py-b123d` and
symlinking the console script back into `/opt/hw-py/bin`.
**Fix `env/setup.sh`, `phase_python()`:** install each MCP server into its own
venv and symlink the entry points, since they are separate processes and share
nothing but the interpreter. Also worth a line in `hw-doctor.sh` output when an
MCP server fails on an import error rather than a missing binary — the two look
identical in the current report and have completely different fixes.

---

**Seven parallel research subagents exhausted the account's five-hour rate
limit.** A workflow fanned out seven agents, each fetching and parsing multi-
megabyte datasheet PDFs. One returned before the quota was spent; the other six
and all seven verification agents died on "You've hit your session limit".
The work was not wrong, only sized wrong: datasheet research is unusually
token-heavy because every PDF arrives as a large blob.
**Fix `skills/hw-sourcing/SKILL.md`:** say plainly that datasheet fan-out should
be serialised or capped at two or three concurrent agents, and that PDFs should
be fetched and extracted locally with pypdf rather than pulled through an agent's
context. There is a working recipe for this already in this repo's history —
the LMG2610 datasheet was extracted successfully that way in the same session
the agents failed.

---

**`WebFetch` cannot read most datasheet PDFs, and the fallback is not
installed.** Agents repeatedly got back "the actual technical specifications are
embedded within the compressed PDF content stream and are not directly
readable", then tried `pdftoppm` and found poppler-utils absent; `apt-get
install poppler-utils` fails because the package is not in the image's sources.
Meanwhile `pypdf` in a clean venv extracts the same documents without trouble.
**Fix `env/setup.sh`:** add `poppler-utils` to the apt phase and `pypdf` to the
Python phase. A hardware toolbox whose central rule is "never take a number from
memory when a datasheet exists" cannot ship without a working PDF text
extractor.

---

**Four workflow stages ran with no human review, because the workflow has exit
conditions but no mechanism.** `docs/02-workflow.md` states an exit condition
for every stage — "the human points at one concept and its numbers without
qualifying", "the human has looked at the image and agreed to it" — and nothing
anywhere causes that to happen. So it did not, four times running: the vision
concepts were rendered and never shown, the StrictDoc HTML export was generated
on every validation run and never mentioned, and the concepts themselves were
built at the wrong scope (two bare coil pads where the human wanted to see a
product) with nobody in a position to catch it.
The cost was not the wasted renders. It was that the vision stage was reported
as complete, and the plan, requirements and architecture were all built on top
of an agreement that had never been made.
**Fix `docs/02-workflow.md` and add `skills/hw-review/`:** make the review an
artefact-producing step with a committed sign-off record, and make "stage is
`done`" conditional on that record existing — the same discipline `req-trace
--gate` applies to evidence, applied to agreement. A draft of the skill is in
this repo at `.claude/skills/hw-review/` and works today; it should move
upstream. The single rule that matters: **an artefact the human has not seen is
not a deliverable.**

---

**A wrong conclusion survived because one configuration was generalised to a
whole technology.** The coil analysis tested a single-layer etched spiral,
found it 70 W short, and wrote up "PCB coils cannot reach the efficiency the
thermal path requires". Parallel layers — the obvious lever — were never
modelled. Six layers turn a 190 W failure into a 73 W pass, so the headline
finding of the project was wrong for two days.
`MEC-001` was unaffected, because it was written against k·Q and dissipation
rather than naming a conductor. That is the requirements discipline doing
exactly its job, and it is why the correction cost an analysis rather than a
requirements rewrite.
**Fix `skills/hw-simulation/SKILL.md`:** add a rule alongside "cross-check
against closed form" — **before concluding that an approach cannot work, list
the design levers you did not vary and say why.** A negative result from one
configuration is a result about that configuration. The existing corner-sweeping
rule covers tolerance, temperature and supply; it does not cover the geometry
and topology choices that are usually the real levers.

---

**Both of the tooling defects logged above are FIXED upstream, and the review
gap is now a first-class stage.** MakeHardware v0.2.0 (commit `93ed502`) lands
`skills/hw-review/`, `bin/review-gate`, `bin/review-artifact`, a
`docs/review/` template and a `review:` field in `plan.yaml` that
`plan-render --check` enforces — so a chunk cannot be called done without a
committed sign-off. It also fixes `block_diagram.py`'s budget roll-up: child
rails are now referred through the voltage ratio, and where a voltage is
missing it rolls up 1:1 and *says so* rather than inventing a ratio.
This session was running v0.1.0 the whole time, from a branch that had since
been deleted upstream, and never checked for an update.
**Fix `skills/hw-doctor` or `hooks/session-start.sh`:** report the installed
plugin commit against the marketplace's current head at session start. A
toolbox whose whole value is current practice should notice when it is running
a version that no longer exists on the remote. The project-local
`.claude/skills/hw-review/` drafted in this session is deleted; the upstream
skill supersedes it and is better.

---

**The block diagram shipped with eight overlapping blocks, and the gate passed
it.** `block_diagram.py` reads hand positions back out of the existing `.drawio`
and pins the layout to them with no collision test. Rev C added seven blocks;
the pre-existing twenty-nine stayed at their rev-B coordinates and eight pairs
landed on top of each other. `block-diagram --check` exited 0, so nothing caught
it and the broken SVG went into a published review packet — the customer found
it. A fresh layout (`--relayout`) has zero overlaps.
**Fix `scripts/block_diagram.py`:** `layout()` should drop or re-flow a kept
position that collides, and `--check` should test the rendered boxes for overlap
rather than validating the spec alone. A gate that passes a diagram nobody can
read is worse than no gate.

---

**Block names are truncated mid-word with no ellipsis.** `render_svg` cuts names
at 24 characters and part numbers at 26. Fourteen of thirty-six blocks were cut,
and "Tank current sense ampli" reads as a typo rather than as an elision — which
is worse than a shortened name, because it makes the whole drawing look
unreviewed.
**Fix `scripts/block_diagram.py`, `render_svg()`:** ellipsize, or wrap onto the
second line the box already has room for, and warn at generation time listing
what was cut so the spec can be shortened deliberately.

---

**One sheet is the only option, and thirty-six blocks do not fit on one.**
Nothing in the generator divides a diagram. At 36 blocks and 23 buses the sheet
is 1376 x 3438 px, the column heuristic interleaves subsystems, and bus labels
print over boxes. Worked around with `scripts/block_sheets.py`, which slices the
master spec by a `sheet:` tag into four subsystem views with stub connectors for
off-sheet endpoints — the master stays the single source of truth so the power
budget still closes across the whole system.
**Fix `scripts/block_diagram.py`:** support a `sheet:` tag natively. Every
project past about twenty blocks needs it, and the master spec has to stay one
file or the budget cannot roll up.

---

**Two generators emit raw HTML that the review renderer escapes.**
`vision_board.py:293` and `review_gate.py:378` both wrap sections in
`<details><summary>`. GitHub renders it; `review_artifact.py` HTML-escapes
everything, so the published review page showed the customer literal
`<details><summary>Dimensioned isometric line drawing</summary>` where a drawing
should have been — in the vision document and in all four review packets.
Worked around with `scripts/md_flatten.py`, which runs after both.
**Fix `scripts/vision_board.py` and `scripts/review_gate.py`:** emit plain
markdown, or give `review_artifact.py` a small tag allowlist. Markdown that only
renders in one of the two places a document is read is the actual defect, and it
is invisible until a human opens the published page.

---

**`vision-board` overwrites the hand-written vision document. Third
occurrence.** `--doc` defaults to `docs/design/vision.md`, which is also where
the narrative lives, so every re-render destroys it; twice it was recovered by
hand and once the loss was only caught by `git diff --stat`. Now pointed at
`docs/design/vision-gallery.md` via `scripts/vision_md.py`.
**Fix `scripts/vision_board.py`:** default the generated gallery to its own
filename, or refuse to overwrite a file it did not itself write.

---

**`MATERIAL` sets the render colour but not the mass.** `vision-board` quotes
mass as `volume x 1.4 g/cm3` whatever the material, and `--material` accepts only
{cobalt, graphite, sand, steel}, so `MATERIAL = "aluminum"` silently fell back to
cobalt. The label does say "at 1.4 g/cm3" so it is not a false statement, but for
an aluminium test rig it reads 23 kg against a real 44 kg — the difference
between a one-person and a two-person lift.
**Fix `scripts/vision_board.py`:** carry a density per material and quote the
mass at it, or omit the mass when the material is not one it knows.

---

**The three-column layout is not fixable from the spec side, so the
architecture views are now drawn outside the plugin.** The customer rejected
`block-diagram`'s output twice. Fixing the stale-position collisions and
splitting into four subsystem sheets was not enough, because the layout engine
itself is the problem: it assigns columns by a heuristic that put eight of the
dock sheet's ten blocks in column one, it routes buses vertically straight
through boxes, and it has no notion of a module, so the dual active bridge was
drawn twice because the master spec instantiates it twice.
`scripts/arch_diagram.py` replaces the views with a stage grid — stages run left
to right in the direction power flows, every vertical run happens in a gutter
that is empty by construction, and a `modules:` section in
`hw/architecture.yaml` draws one design once however many times it is built. The
master spec still owns all content and still feeds the power budget.
**Fix `scripts/block_diagram.py`:** the useful primitives are a stage/flow
direction per block, gutter routing rather than free vertical runs, and module
instancing. Without those, any power-electronics diagram past a handful of
blocks comes out unreadable, and the gate cannot tell — `--check` passed every
version the customer rejected. A geometric assertion that no wire crosses a box
is four lines and would have caught all of it.

---

**The review page's architecture tab shows one hardcoded figure and ignores the
review's artefact list.** `phase_architecture` in `review_artifact.py` calls
`figure(root, "docs/design/block-diagram.svg", ...)` and nothing else, so four
artefacts sent for review arrived as one diagram on the published page. The
customer, whose only access is that page, reported seeing a single drawing.
`review-gate open --artifact` and `review-artifact`'s figures are two unrelated
mechanisms, and nothing says so.
Worked around with `docs/review/artifact.yaml`, which has a second cost: `hide`
suppresses a configured phase of the same id as well as the standard one, and a
review binds to a phase BY ID, so replacing the architecture tab forces the
review id to change from `architecture` to `arch` to keep the questions on the
same tab as the drawings.
**Fix `scripts/review_artifact.py`:** every standard phase should show the
artefacts its review actually lists, falling back to the hardcoded path only
when the review has none. Failing that, `hide` should not suppress a configured
phase that is replacing a standard one of the same id.

---

**A sheet wider than the review column is scaled down bodily, with no warning
and no horizontal scroll.** `.sheet svg{width:100%}` means a 2120 px diagram
arrives in a ~1150 px column at 54%, turning 12 px labels into 6 px. Nothing in
`--check` mentions it — the page reports "clear" — and it is invisible until a
human opens the page and cannot read it. Every architecture sheet is now laid
out to land under 1160 px and `arch_diagram.py --check` fails if one does not.
**Fix `scripts/review_artifact.py`:** either put an oversized figure in an
`overflow-x:auto` container, as the tables already are, or warn at generation
time with the effective scale, the way an oversized raster is already reported.
A diagram nobody can read is the same defect as a diagram that did not embed.

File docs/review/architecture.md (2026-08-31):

# Review — Architecture — three modular sheets

`architecture` · requested 2026-08-31 · branch `claude/wireless-charging-design-hf0aix`

Rebuilt 2026-08-31 after you rejected the previous two attempts. You were right that the column grid was the problem, not just the collisions: the generator's heuristic put eight of the dock sheet's ten blocks in one column, routed buses straight through boxes, and drew the dual active bridge twice because the master spec instantiates it twice. The views are now drawn by scripts/arch_diagram.py on a stage grid — stages run left to right in the direction power flows, and every vertical run happens in a gutter that is empty by construction, so a wire cannot cross a box. That is now asserted geometrically rather than checked by eye: all three sheets report zero wire-over-box crossings. Three sheets. SYSTEM is the whole power path in one row: 48 V Leviathan pack, dock DAB, transmitter, air gap, receiver, vehicle DAB, 48 V Mako pack. DAB is the dual active bridge drawn ONCE, each box carrying both instance designators (U40 / U22 and so on) — one design, one schematic, one firmware image, with direction as a configuration item. LINK is the transmitter, coils and receiver as a logical chain with control below it. The master spec still owns every part, rail and current, and block-diagram.svg is kept as the power-budget sheet because that is where the rail headroom bars live.

## What you are agreeing to

**arch-dab.svg**



**arch-link.svg**



**arch-system.svg**



**block-diagram.svg**



## For context

Sources and working files. Not part of the agreement — these change as work goes on, and changing them does not invalidate your sign-off.

| File | Opens in |
|---|---|
| [hw/architecture.yaml](https://github.com/Harwasch/makehardware_Test/blob/claude/wireless-charging-design-hf0aix/hw/architecture.yaml) | plain text on GitHub |
| [hw/block-diagram.yaml](https://github.com/Harwasch/makehardware_Test/blob/claude/wireless-charging-design-hf0aix/hw/block-diagram.yaml) | plain text on GitHub |

## What we need decided

1. Do the three sheets read now — system power path, the DAB drawn once, and the TX/coils/RX chain?
2. The dock DAB has no debug header where the vehicle instance has J4. If it really is one design built twice, that asymmetry is a defect in the master spec. Should I add one?
3. V48_LEV and V48_MAKO both sit at 95% of the 80 A their connectors can deliver. I would rather size the connectors up now than find it at layout. Do you want that?

## Decision

**Not yet reviewed — this is waiting on you.**

Answer in the Claude session that sent you this link. There is nothing to run and nothing to sign here.

Say which option you want **and why**: the reason is worth more than the choice, and it is what gets re-read later when a number has to move. If something is wrong, say what would be right.

**How the answer gets recorded**

The agent writes your decision, in your words, into [`docs/review/reviews.yaml`](https://github.com/Harwasch/makehardware_Test/blob/claude/wireless-charging-design-hf0aix/docs/review/reviews.yaml):

```bash
review-gate sign architecture --approve --by <name> --note "..."
review-gate sign architecture --changes "what to change"
```

Until that happens, any chunk of work depending on this review cannot be marked done.

---

<sub>Generated by `review-gate`. The sign-off record is [`docs/review/reviews.yaml`](https://github.com/Harwasch/makehardware_Test/blob/claude/wireless-charging-design-hf0aix/docs/review/reviews.yaml).</sub>

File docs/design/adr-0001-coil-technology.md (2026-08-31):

# ADR-0001 — Coil technology

**Status:** Accepted.
**Date:** 2026-08-29
**Chunk:** M2 · **Gate:** G1 (delegated decision)

## Decision

**Keep the PCB coil.** Specifically: a **fully transposed multi-track PCB
winding** — not a plain parallel-layer stack — with traces near one skin depth,
and **the mounting structure specified as the heat sink**.

| | |
|---|---|
| Pad | 102 × 203 mm (4 × 8 in), fixed |
| Construction | multi-track, **transposed** layer-to-layer |
| Turns | **24** |
| Trace / space | **0.25 mm / 0.20 mm** — skin depth at 85 kHz is 0.26 mm |
| Copper | **4 oz** (0.14 mm, 0.54 skin depths) |
| Layers | **16** in parallel · 12 is the floor |
| Mutual inductance | 94.6 µH at worst case, against 80.9 µH required |
| **k·Q, worst case** | **75.0** at 16 layers · 61.1 at 12 · requirement **49** |
| Pad dissipation | **39 W** at 16 layers · 48 W at 12 |
| Bracket external area | **≥ 14× the pad footprint** |

Sized against the **binding condition**, which is the 14 mm gap with 5 mm of
offset — the far corner of the `SYS-006` envelope, not the nominal. At the
10 mm nominal it reaches k·Q = 109 and 27 W per pad.

## Context

`MEC-001` allows the coil pair 120 W of 3 kW, which is k·Q ≥ 49. Across the
`SYS-006` envelope the computed coupling is 0.645 at the 10 mm nominal gap, so
the coil must reach **Q ≈ 76**. The customer prefers PCB for manufacturability
and inductance repeatability, and the earlier analysis in this repo claimed a
six-layer plain stack would reach Q = 176. **That claim was wrong**, and the
research commissioned to defend it refuted it instead.

## The defect that produced the wrong answer

`coil_rect.py` computed `r_dc = rho·length/(w·t·layers)` and then multiplied by
the proximity factor. **That divides the proximity loss by N as well**, which is
physically wrong.

Proximity resistance is proportional to conductor volume and to B², and is
**independent of the current the conductor carries** — Nguyen & Fortin
Blanchette, *Electronics* 2020, **9**, 1324, Eq. 2. Parallel layers do not
change total ampere-turns, so B is unchanged: each layer added is another slab
of copper eddy-heating in the same field. Transport loss falls as 1/N;
proximity loss **rises** as N:

> **R_ac(N) = R_dc1 / N + N · R_prox1**, minimum at N_opt = √(R_dc1 / R_prox1)

Measured confirmation of the exact experiment: **Yin et al., *Electronics* 2024,
**13**, 426, Table 12** — a 90 mm PCB spiral (8 turns, 2.8 mm trace, 2 oz) at
100 kHz. One layer: 189 mΩ, Q 17.44. Two identical layers in parallel:
159 mΩ, Q 20.81. **A 15.9% resistance reduction where 1/N predicts 50%** — an
effective exponent of N^−0.25, worse than 1/√N. (The parallel identification is
inferred: self-inductance is unchanged at 5.25→5.27 µH, whereas their series
build measures 20.85 µH, i.e. 4×, as series-aiding coupled coils must. The
paper does not use the word "parallel", so this is a strong inference, not the
authors' own statement.)

With the model corrected, the best **plain parallel** design on our pad reaches
**k·Q = 46.4 against the 49 required** — it fails, by 5%.

## Why transposition rescues it

The penalty is not intrinsic to PCB; it is intrinsic to *stacking layers that
each sit permanently at a different depth in the field*. Transposing the stack,
so every layer spends equal time at every depth, is the published fix.

**Lewis, Onar et al. (ORNL / University of Kentucky), ECCE 2024** built exactly
our case — a multi-layer PCB coil at 85 kHz for an 11 kW wireless charger. With
straightforward sequential layering their 3D FEA found up to **31% difference in
induced voltage and 50% difference in self-inductance between parallel layers**.
Deliberate layer-to-layer transposition cut those to **0.4% and 0.7%**,
validated to under 1% on a fabricated prototype. The same team sized their
85 kHz conductor to **exactly one skin depth: 0.22 mm trace, 0.25 mm space,
1 oz** — which is where our 0.30 mm trace comes from, and why the earlier
0.80 mm choice was wrong in both directions (too wide to stack well, too narrow
for a single-layer optimum).

The consequence of *not* transposing is stated bluntly elsewhere. Li et al.,
*IET Power Electronics* 2018, refuse parallel layers outright: "the current does
not distribute equally between each layer, the current in certain layers may
[be] extremely high with the increasing of the operating frequency." Lloyd
Dixon's Unitrode note **SLUP125** puts it more sharply still for the transformer
case: parallel five strips one skin depth thick and essentially all the
high-frequency current flows in the one nearest the field source.

**The measured anchor.** Narvaez, Carretero, Lope, Acero and colleagues
fabricated and measured a **fully transposed multi-track PCB coil** for wireless
power. At 85 kHz, on a ~380 mm pad, it measured **Q = 153**, against **Q = 260**
for a copper-Litz WPT3 pad of the same footprint from the same lab. Litz wins by
1.7× on Q — **and the transposed PCB coil is still comfortably above what this
design needs.**

At the chosen 24 turns / 0.25 mm / 4 oz / 16 layers, at the worst corner of the
envelope:

| Transposition | k·Q | Per pad | vs 49 |
|---|---|---|---|
| None — plain parallel stack | 45.2 | 66 W | **fails** |
| Half effective | 60.9 | 48 W | passes, 1.24× |
| **Fully transposed** | **75.0** | **39 W** | **passes, 1.53×** |

**The decision survives transposition being only half as effective as intended.**
That is the margin it rests on, and it is why this is a defensible choice rather
than a marginal one — but it also shows how completely it depends on
transposition happening at all.

## The binding constraint is thermal, and it leaves through the mount

This is the finding that actually shapes the design, and it is not electrical.

A flat plate in still air sheds roughly **150 W/m²** at an acceptable
temperature rise; forced air reaches about 2000 W/m². Our 207 cm² pad therefore
sheds about **3.1 W from its own faces**. We need to remove **36 W** — twelve
times that.

**The pad face is irrelevant. All of the heat leaves through the mounting
structure.** At 36 W/pad that structure needs roughly **2400 cm² of external
surface — about 12× the pad footprint**. A 400 × 500 mm finned aluminium plate
provides that comfortably, which is precisely why the decision to charge on deck
in a fixture makes this work. Had the pad been hull-mounted with only its own
faces to work with, no coil technology would have saved it.

**This makes the mount a thermal component, not a fixture**, and it is now
`MEC-009`.

Since 2026-08-31 the fixture belongs to the mechanical team (`VIS-013`), which
changes who satisfies `MEC-009` but not whether it holds. It is stated as an
**interface requirement** on the integrator, and met directly in the test
packaging. This ADR's conclusion depends on it: an etched coil is viable
*because* something with 2400 cm² cools it. If that surface is not there in the
delivered installation, this decision does not hold and the coil technology has
to be revisited.

## Consequences

**Good.** The customer keeps PCB, with its inductance repeatability, its absence
of a winding operation, and its tolerance to fabrication scatter — and it is now
backed by a measured comparable rather than by a model. Fine traces near one
skin depth also nearly remove in-plane proximity effect, so the design sits in a
regime where the physics is well understood.

**Bad, and load-bearing.** *Transposition is not optional.* A plain stack misses
the requirement, and a plain stack is what a PCB house will produce unless the
layer interconnect is specified deliberately. This has to be carried explicitly
into the layout rules and checked at fab.

**Bad.** The transposed prediction is **optimistic against the one comparable
measurement**. The model puts our smaller pad at Q = 164; Narvaez measured 153
on a pad 3.7× larger, and Q scales with size, so the real figure is likely well
below 164. The decision survives that de-rating — at Q = 100 the design still
gives k·Q = 65 — but the headline number should not be quoted as a prediction.

**Bad, and the most concrete warning available.** Narvaez's transposed PCB coil,
at 3.3 kW — essentially our power level — measured **93% coil-to-coil, not the
96% we budget**, and in their thermal run the receiver reached **90.3 °C and was
still rising when power was cut at 33 minutes**. A published transposed PCB coil
at our power did not reach thermal equilibrium in half an hour. That is the
risk this ADR accepts, and `MEC-009` is what must retire it.

**Bad, and it cuts against the reason PCB was chosen.** Sixteen layers at 4 oz
is **64 oz of copper in one board**. That is a heavy-copper multilayer at the
far edge of standard capability, not the cheap commodity board the PCB choice
was meant to buy — and the via stitching that makes the transposition work adds
its own resistance and its own fabrication risk. **A fab-capability check is
required before this is committed**, and it is the first thing that could send
the decision back to Litz. Twelve layers is the floor that still passes
(k·Q = 61.1, 48 W/pad) if sixteen proves unbuildable.

The alternative of thinner copper on more layers is worse, not better: 2 oz on
20 layers reaches k·Q = 52.7 and only passes if transposition is nearly perfect,
where 4 oz on 12 passes even at half effectiveness.

## Alternatives considered

* **Litz wire.** Measured Q = 260 against the transposed PCB's 153 on the same
  footprint — genuinely better, by 1.7×. Rejected because the PCB option now
  meets the requirement with margin, and Litz reintroduces a winding operation,
  a wound-part tolerance, and a supplier the customer explicitly wants to avoid.
  **Held as the fallback** if `MEC-009` proves the thermal path cannot be built.
* **Plain parallel layers.** k·Q = 46.4 against 49. Rejected on the arithmetic.
* **Wider traces, fewer layers.** The direction the earlier analysis took. The
  joint sweep over trace width and layer count puts every wide-trace option
  below every narrow-trace one; 0.80 mm with 4 layers reaches k·Q = 35.
* **Solid copper planar coil.** Higher Q than PCB but no longer a PCB process,
  and it forfeits the repeatability that motivated the choice.

## Verification status

Every number attributed to a source above was returned by a research agent and
then **adversarially re-checked by a second agent that went back to the primary
sources**. That check returned `minor-corrections` on the multilayer topic and
`major-corrections` on the Litz comparison — several figures in the first pass
were misread, and one claim labelled "measured" was in fact calculated. The
figures retained here are the post-correction ones.

**One gap:** the verification pass on the ferrite and thermal topic **did not
run** — the account hit its rate limit. So the 150 W/m² natural-convection
figure and the bracket area that follows from it are **researched but
unverified**, and `MEC-009` must not be closed against them without a second
source.

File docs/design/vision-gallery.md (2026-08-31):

# Vision — this product

What we think you asked for, drawn from real geometry. Every image below comes from a parametric model, so nothing here is a shape that cannot be built, and every number is measured off the model rather than estimated.

## Test packaging — pin-located, shim-set gap

A bench rig, not a fixture prototype. Each pad sits on two 8 mm dowels in a hole-and-slot pattern (MEC-010) so it lands in the same place every time without the pin spacing fighting the holes. The upper platen carries the RX pad face-down; the coil-to-coil gap is set by the shim stack under the four columns and read with the same gauge that verifies it, which is what SYS-017 needs to hold 8-14 mm to 0.5 mm. Lateral offset to 5 mm and tilt to 2 degrees come from shimming one column pair against the other. Each pad conducts into a 340 x 380 mm finned sink giving 8,104 cm2 against the 207 cm2 pad -- 39 times the footprint where MEC-009 asks for 12. That margin is deliberate and should NOT be read as the thermal case being closed: MEC-009's 12x is a flat-plate-equivalent figure at 150 W/m2, and a finned surface does not convect per unit area the way a flat plate does. Fin efficiency and channel convection are still owed by the thermal chunk. The rig stands on four feet that lift the lower sink clear of the bench, so its fins see air.

**692.0 × 410.0 × 252.0 mm** · 16,459,394 mm³ · ~23,043 g at 1.4 g/cm³ · model: `concepts/test_packaging.py`

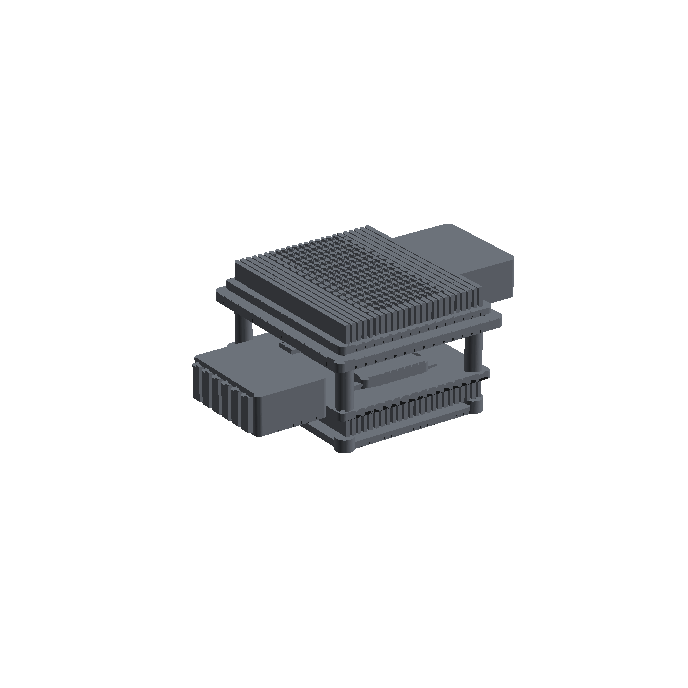
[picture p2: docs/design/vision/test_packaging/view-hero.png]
Test packaging — pin-located, shim-set gap — three-quarter view


| Front | Top |
|---|---|
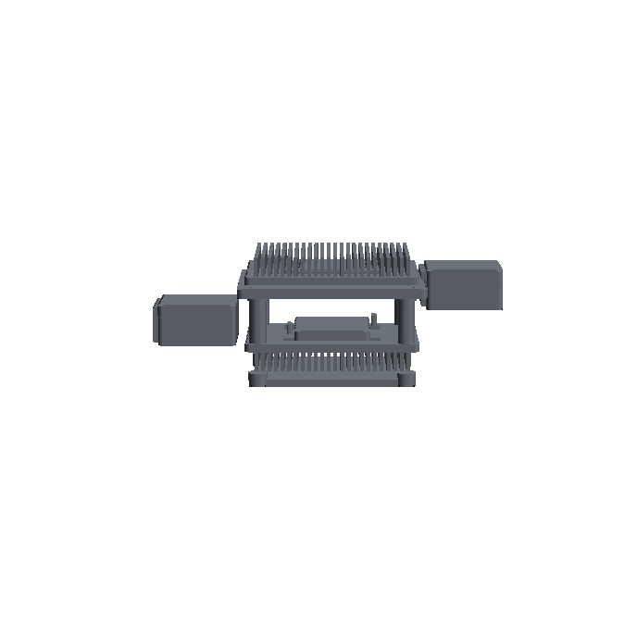
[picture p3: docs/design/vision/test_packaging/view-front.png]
front
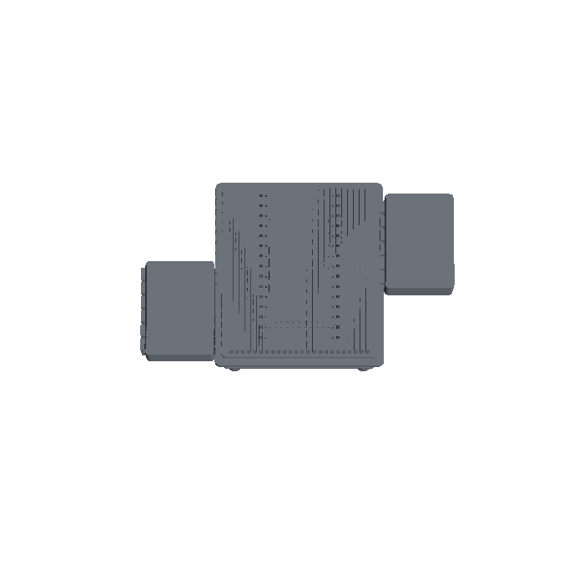
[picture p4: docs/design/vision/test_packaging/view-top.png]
top
|  |  |

[Dimensioned isometric line drawing →](vision/test_packaging/iso.svg)

## What we need from you

1. Which concept, and what made you pick it? The reason matters more than the choice.
2. Is anything in the envelope wrong — too big, too small, wrong proportions?
3. What is missing that you assumed we knew?

Whatever you agree to here becomes the `VIS-` entries in `requirements/00-vision.sdoc`, in your words, and everything downstream is built on it.

---

<sub>Generated by `vision-board` from the models in `concepts/`. Change a parameter and re-run; do not edit this file.</sub>

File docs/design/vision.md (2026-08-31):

# Vision — Ulysses LARS Charger, revision 2

Captured 2026-08-28, decided at [gate 1](reviews/gate-1-vision.md), scope
narrowed 2026-08-31. Source material: the v1 white paper and firmware, reviewed
in [`v1-baseline.md`](v1-baseline.md). Agreed intent lives in
[`requirements/00-vision.sdoc`](../../requirements/00-vision.sdoc) as `VIS-001`
through `VIS-013`.

**Scope: the charger electronics, plus a test packaging.** `VIS-013`. The
converters, the coil pair and their control are ours. Integration — the deck
fixture, the vehicle mounting, the handling — belongs to the mechanical team.
The vehicle is not modelled. What we build in metal is a bench rig that holds
the coil pair at the `SYS-006` envelope so the magnetics can be measured.

**The pads locate on pins.** `VIS-005`, set 2026-08-31. A two-pin hole-and-slot
pattern, in the delivered system and in the test rig alike.

## The thing, in one paragraph

A 3 kW magnetic-resonant wireless charger that moves power from a 400 V bus on
the Leviathan dock to a 48 V pack in the Mako, across a gap that is never
bridged by a connector. The dock holds the vehicle close and square, so the
coils couple well. Nothing is pumped or fanned — every watt the system wastes
has to conduct out through the structure it is bolted to.

## What changed when we asked

The white paper is a complete technical brief, so the vision interview was
short and about the four numbers it never states. All four turned out to matter:

| Question | Answer | What it changed |
|---|---|---|
| Pack voltage and capacity | 48 V, 33 Ah (1.58 kWh), growing in Ah not volts | 3 kW is 1.9C today — the pack, not the charger, is the present limit. 3 kW is for the future pack. |
| Air gap and alignment | < 20 mm, well aligned | k ≈ 0.5 rather than the ≈ 0.2 the EV literature assumes. A real advantage, currently unspent. |
| How firm is 3 kW | Design for it, let physics move it | Licence to report honestly when a number cannot be met. |
| Cooling | Conduction to chassis only | **This is the constraint that decides the magnetics.** |

## The decision this vision turned on

Coil-to-coil efficiency in an inductive link is governed by the product of
coupling and quality factor, **k·Q** — not by resistance alone:

> η_max = (kQ)² / (1 + √(1 + (kQ)²))²

`MEC-001` allows the coil pair 120 W of 3 kW, which is **k·Q ≥ 49**. Charging on
deck in a pin-located fixture sets the gap by two housing walls rather than a
vehicle hull, which buys a coupling of 0.43–0.57 across the `SYS-006` envelope.

**The coil is an etched PCB**, decided in
[ADR-0001](adr-0001-coil-technology.md) and backed by published measurements:
24 turns of 0.25 mm trace in 4 oz copper, **16 transposed layers**, reaching
k·Q = 75.0 at the worst corner. A plain parallel-layer stack of the same
geometry reaches 45.2 and fails — parallel layers do not reduce resistance as
1/N, and transposition is what makes the difference.

The binding constraint turned out to be **thermal, not electrical**: the pad
sheds about 3 W from its own faces and must lose 39 W, so every watt leaves
through the structure the pad is bolted to. That is `MEC-009`, and it is why the
deck-mount decision is what makes an etched coil viable at all.

Note what the scope change did *not* do. The fixture became the mechanical
team's, but `MEC-009` was **re-aimed, not withdrawn** — it is now an interface
requirement we levy on whoever builds that structure, and one the test packaging
must meet itself. Handing over a coil without handing over its heat-sink
requirement is how a design that closed on paper arrives at a 90 °C pad.

## What we build in metal

One thing, and it is test equipment: a rig that holds the two pads at a known
gap and offset while the magnetics are measured. It is not a prototype of the
deck fixture and is not marine, recoverable or handled.

Three locating-feature concepts were studied at gate 1 — a kinematic
cone-vee-flat mount, tapered rails and a perimeter nest. **All three are
withdrawn**: they were fixture designs, and the fixture is not ours. Pins were
chosen from among them as the interface, because a two-pin hole-and-slot pattern
is the cheapest thing that fixes six degrees of freedom to the tolerance
`SYS-006` needs, is producible under `MEC-006` with no programme tooling, and
leaves the pad faces clear for the thermal path.

The rig is rendered in **[`vision-gallery.md`](vision-gallery.md)**, from the
parametric model in [`concepts/test_packaging.py`](../../concepts/test_packaging.py).
Its envelope is 692 × 410 × 252 mm. The gallery quotes mass at 1.4 g/cm³, which
is the tool's fixed assumption and wrong for this part — in aluminium the solid
model is about 44 kg, and the built rig somewhat less because the electronics
enclosures are drawn as solid blocks. Either way it is a two-person lift, not a
bench-top item.

Each pad conducts into a 340 × 380 mm finned sink giving 8,104 cm² against the
207 cm² pad — 39 times the footprint where `MEC-009` asks for 12. **That margin
should not be read as the thermal case being closed.** `MEC-009`'s 12× is a
flat-plate-equivalent figure at 150 W/m², and a finned surface does not convect
per unit area the way a flat plate does; fin efficiency and channel convection
are still owed by the thermal chunk. The 150 W/m² figure itself is still
single-sourced and unverified.

## What we need from you

1. Is the scope line right — electronics plus a test rig, with integration and
   the fixture going to the mechanical team?
2. Pins: two dowels, hole and slot. Anything about the real fixture that would
   make a different interface better?
3. Is 8–14 mm of gap and 5 mm of offset the envelope the fixture can actually
   hold? It is currently *our assumption about someone else's part*, which is
   the weakest thing in this document.
4. Is anything in the rig's envelope wrong — too big, too small, wrong
   proportions?

## What v2 keeps from v1

The two-stage resonance tracking — a static frequency sweep that lands near
resonance, then a hill-climb that converges — is the one thing the white paper
actually demonstrated on a bench, and it should survive intact. The firmware
underneath it needs work (thirteen findings in the baseline, five of which
change behaviour on hardware), but the control architecture is sound.

## What is still open

* Cell charge acceptance for the present 48 V / 33 Ah pack — sets the maximum
  rate that may actually be commanded today, and needs the pack datasheet.
* Whether bidirectional operation is required at all. The DAB is bidirectional;
  nothing in the brief asks the Mako to export power. If it is not needed, the
  HV side simplifies considerably.
* The dock and vehicle ambient temperature, which sets what "conduction to
  chassis" is actually worth in °C/W.
* The gap and misalignment the mechanical team's fixture can actually hold.
  `SYS-006` states 8–14 mm and 5 mm as what the magnetics tolerate, which is the
  right way round, but it is still an assumption about a part we do not design.
* The 150 W/m² still-air figure behind `MEC-009`'s 12× surface area. Researched,
  single-sourced, never independently confirmed; the verification pass on it did
  not run.

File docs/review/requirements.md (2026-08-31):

# Review — Requirements — 69 requirements, 0% verified

`requirements` · requested 2026-08-31 · branch `claude/wireless-charging-design-hf0aix`

Re-opened 2026-08-31 for the scope change. Three requirements moved and three are new. VIS-013 states the scope: charger electronics plus a test packaging, integration to the mechanical team. VIS-005 and SYS-006 now say pins rather than an unnamed locating feature. SYS-017 and MEC-010 specify the test packaging — it has to set the SYS-006 envelope to 0.5 mm, because MEC-001 and MEC-003 are both written across that envelope and are closest to failing at its corners. The one to read carefully is MEC-009. It was 'the mounting bracket is the heat sink' and the bracket is no longer ours; rather than delete it with the bracket, it is re-aimed as an interface requirement we levy on whoever builds the mount, and one the test rig must meet itself. The pad sheds 3 W from its own faces and has to lose 39 W, so handing over the coil without handing over its heat-sink requirement is how a design that closed on paper arrives at a 90 degC pad. Coverage is 0% verified and that is correct — no design artefact exists yet, so every gap is a missing evidence pointer, not a defect. Nothing has been marked Verified to improve the number.

## What you are agreeing to

**requirements-map.svg**



| File | Opens in |
|---|---|
| [requirements/00-vision.sdoc](https://github.com/Harwasch/makehardware_Test/blob/claude/wireless-charging-design-hf0aix/requirements/00-vision.sdoc) | StrictDoc source |
| [requirements/10-system.sdoc](https://github.com/Harwasch/makehardware_Test/blob/claude/wireless-charging-design-hf0aix/requirements/10-system.sdoc) | StrictDoc source |
| [requirements/20-electrical.sdoc](https://github.com/Harwasch/makehardware_Test/blob/claude/wireless-charging-design-hf0aix/requirements/20-electrical.sdoc) | StrictDoc source |
| [requirements/20-firmware.sdoc](https://github.com/Harwasch/makehardware_Test/blob/claude/wireless-charging-design-hf0aix/requirements/20-firmware.sdoc) | StrictDoc source |
| [requirements/20-mechanical.sdoc](https://github.com/Harwasch/makehardware_Test/blob/claude/wireless-charging-design-hf0aix/requirements/20-mechanical.sdoc) | StrictDoc source |
| [requirements/README.md](https://github.com/Harwasch/makehardware_Test/blob/claude/wireless-charging-design-hf0aix/requirements/README.md) | renders on GitHub |
| [requirements/hardware.sgra](https://github.com/Harwasch/makehardware_Test/blob/claude/wireless-charging-design-hf0aix/requirements/hardware.sgra) | download |

## What we need decided

1. MEC-009's 12x surface area comes from a single unverified 150 W/m2 still-air figure, and the whole thermal case rests on it. Do you have a second source, or should I spend a chunk confirming it?
2. Is SYS-017's 0.5 mm gap-setting repeatability achievable with shims in your shop, or should the rig use a micrometer stage?
3. Are the numbers right — 3.0 kW, 120 W to the coil pair, k times Q of 49, 8-14 mm?

## Decision

**Not yet reviewed — this is waiting on you.**

Answer in the Claude session that sent you this link. There is nothing to run and nothing to sign here.

Say which option you want **and why**: the reason is worth more than the choice, and it is what gets re-read later when a number has to move. If something is wrong, say what would be right.

**How the answer gets recorded**

The agent writes your decision, in your words, into [`docs/review/reviews.yaml`](https://github.com/Harwasch/makehardware_Test/blob/claude/wireless-charging-design-hf0aix/docs/review/reviews.yaml):

```bash
review-gate sign requirements --approve --by <name> --note "..."
review-gate sign requirements --changes "what to change"
```

Until that happens, any chunk of work depending on this review cannot be marked done.

---

<sub>Generated by `review-gate`. The sign-off record is [`docs/review/reviews.yaml`](https://github.com/Harwasch/makehardware_Test/blob/claude/wireless-charging-design-hf0aix/docs/review/reviews.yaml).</sub>

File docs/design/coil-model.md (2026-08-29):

# Coil model — inductance, coupling and quality factor by analysis

> **CORRECTED 2026-08-28.** An earlier version of this document concluded that
> an etched PCB coil could not meet `MEC-001` and that Litz was required. **That
> conclusion was wrong**, and wrong in a way worth naming: it rested on a
> *single-layer* analysis that was then generalised to "the etched spiral" as a
> category. Parallel layers are the obvious lever and were never modelled.
> The corrected result is in [Result 4](#result-4--the-rectangular-pcb-coil-that-works)
> — a 4 × 8 inch, six-layer PCB coil clears the requirement with 1.57× margin.
> The circular single-layer analysis below is kept because its method is sound
> and its intermediate results still hold; only the conclusion drawn from it was
> overreaching.

Chunk **M1**. Written without laboratory access, so every number here is a model
output and the caveats are part of the result. Reproduce with:

```bash
cd sim/coil
/opt/hw-py/bin/python coil_rect.py         # THE DESIGN — rectangular, multilayer
/opt/hw-py/bin/python coil_model.py        # circular inductance and coaxial coupling
/opt/hw-py/bin/python coil_coupling.py     # coupling across the misalignment envelope
/opt/hw-py/bin/python coil_resistance.py   # AC resistance and quality factor
```

## Method, and why each part is trusted differently

| Quantity | Method | Confidence |
|---|---|---|
| Self-inductance | Filament summation with Maxwell's elliptic-integral mutual term, cross-checked against the Mohan current-sheet fit | **High** — the two agree to 2.6–4.2% |
| Coupling, coaxial | Maxwell's formula, exact for coaxial filaments | **High** |
| Coupling, misaligned | Neumann double integral, numerical | **High** — validated against the analytic coaxial result to 0.14% |
| PCB AC resistance | Kuhn & Ibrahim planar-spiral model | **Low** — used three orders of magnitude outside its fitted trace width |
| Litz AC resistance | DC from geometry, `F_R` swept rather than predicted | **Low–medium** |
| Ferrite and cold-plate effects | Not modelled | **Absent** — needs FEA |

The last three rows are why this document settles a direction and not a design.

## Result 1 — the dock's tight gap is worth much more than assumed

The vision interview gave "under 20 mm, well aligned", which I turned into an
assumed **k ≈ 0.5** taken from the EV wireless-power literature. That was
conservative to the point of being wrong. Computed for the real geometry:

| Gap | Lateral | Tilt | k |
|---|---|---|---|
| 5 mm | 0 | 0° | 0.918 |
| 10 mm | 0 | 0° | 0.841 |
| 20 mm | 0 | 0° | 0.711 |
| **20 mm** | **10 mm** | **0°** | **0.705** ← worst in the `SYS-006` envelope |

The EV literature's k ≈ 0.2 comes from a 100–200 mm gap between 300–400 mm pads,
a gap-to-diameter ratio of 0.3–0.5. Here it is 20/300 = **0.067**. Misalignment
across the whole allowed envelope costs less than 1% of k, because a 10 mm
lateral offset is small against a 200 mm mean diameter.

Two things follow:

* **The coil needs less inductance than stated.** M must be 80.9 µH for 3 kW at
  resonance; at k = 0.705 that is **115 µH per side, not 162 µH**.
* **The quality-factor requirement relaxes.** `MEC-001` fixes k·Q ≥ 49; at
  k = 0.705 that is **Q ≥ 69, not Q ≥ 98**.

`MEC-003`'s 0.40 floor now has a 1.76× margin. It should stay at 0.40 — the
margin is what absorbs the ferrite and cold-plate corrections that are not yet
modelled.

## Result 2 — the resized coils

| | **PCB spiral** | **Litz** |
|---|---|---|
| Turns | 24 | 25 |
| Inductance | 116 µH | 124 µH |
| Conductor length | 15.1 m | 15.7 m |
| Conductor | 3.0 × 0.14 mm (4 oz) | 3.2 mm bundle, ~800 × AWG 40 |
| Copper cross-section | 0.42 mm² | 4.02 mm² — **9.6×** |
| Radial pitch / clearance | 4.35 / 1.35 mm | 4.17 / 0.97 mm |
| k at 20 mm | 0.709 | 0.722 |

**The v1 trace width does not fit.** At 5 mm, the turn count needed for this
inductance demands a 3.57 mm pitch — narrower than the trace. A 5 mm etched coil
at this inductance needs two layers in parallel or a larger diameter.

## Result 3 — quality factor, and the decision it points at

Skin depth in copper at 85 kHz is 0.226 mm, so 4 oz copper at 0.140 mm is
0.62 skin depths — skin effect *through the thickness* is mild. The problem is
**proximity effect between adjacent turns**, and it is what separates the two
conductors.

| Coil (hot, 100 °C, winding only) | Q | k·Q | η | Loss at 3 kW |
|---|---|---|---|---|
| PCB spiral | 43 | 31 | 93.7% | **190 W** |
| Litz, F_R = 4.0 (pessimistic) | 187 | 135 | 98.5% | 44 W |
| Litz, F_R = 2.0 | 374 | 270 | 99.3% | 22 W |
| **Requirement** | **≥ 69** | **≥ 49** | **≥ 96.0%** | **≤ 120 W** |

The etched spiral misses the budget by 70 W **before** ferrite core loss and
cold-plate eddy loss are added, and both only make it worse. Litz clears it with
room even at a pessimistic proximity factor.

A detail worth keeping: the PCB spiral's Q is 43 at both 24 and 29 turns. Q is a
property of the conductor cross-section and the frequency, not of the turn
count, because R and ωL scale together. **You cannot wind your way out of a bad
conductor.**

## Corrections to previously reported figures

The vision-stage analysis scaled v1's stated 12 µH / 0.8 Ω coil to the required
inductance and predicted Q ≈ 29 and 381 W. Computing from real geometry instead
gives **Q ≈ 43 and 190 W**. The etched coil is better than that first estimate
said — it still misses the requirement, but by 70 W rather than 261 W. The
earlier figure inherited v1's resistance number, which the same review had
already found to be inconsistent with v1's own stated frequency, so it should
not have been used as a basis.

## What this cannot settle

1. **Ferrite backing.** Raises both L and k, and adds core loss that a measured Q
   would include. No closed form. Needs magnetostatic FEA.
2. **Cold plate.** A conductive plate behind the ferrite carries eddy currents
   that lower L, lower k and add loss, and it sets a minimum ferrite thickness.
3. **The PCB proximity factor**, per the caveat above.
4. **Seawater in the gap.** Conductive and lossy at 85 kHz; `SYS-005` allows
   immersion, so this is a real operating condition and not a corner case.

Until those are modelled, `MEC-001` cannot be marked satisfied. The honest
status is that analysis points firmly at Litz and rules the etched spiral out
by a margin larger than the modelling uncertainty — which is enough to proceed
with M2, and not enough to close the requirement.

---

## Result 4 — the rectangular PCB coil that works

The house constraint is a roughly **4 × 8 inch rectangular** PCB coil with
passive cooling. `coil_rect.py` handles that geometry directly — Grover's
rectangular-loop formula for each turn's self-inductance, numerical Neumann
integration for every turn pair and for the coil-to-coil mutual, so gap, lateral
offset and tilt all work without a symmetry assumption.

### The rectangle costs coupling, and fine traces buy it back

| | 300 mm circular | **102 × 203 mm** |
|---|---|---|
| Coupling k at 20 mm | 0.705 | **0.461** |
| Turns to reach M = 80.9 µH | 24 | **32** |
| Trace width that fits | 3.0 mm | **0.80 mm** |
| R_ac / R_dc | 1.77 | **1.06** |

The coupling penalty is geometric: a 20 mm gap is 20% of the short dimension
here, against 7% of the 300 mm diameter. That is the price of the smaller pad.

The compensation is unexpected and useful. Driving the trace to 0.80 mm
**almost eliminates proximity effect** — the AC/DC resistance ratio falls from
1.77 to 1.06, because the Kuhn–Ibrahim critical frequency scales as
(w + s)/w² and rises steeply as the trace narrows. The coil stops being a
proximity problem and becomes a **pure DC-resistance problem**, which is
precisely what parallel layers fix.

### Layers are the lever — but NOT as 1/N

> **CORRECTED AGAIN, 2026-08-29.** The table below assumed parallel layers cut
> resistance by 1/N. **They do not**, and the error was in this repo's own code:
> dividing R_dc by the layer count and then applying the proximity factor
> divides the proximity loss by N as well. Proximity loss is independent of the
> current a conductor carries, so it *rises* as N. The corrected model is
> `R_ac(N) = R_dc1/N + N·R_prox1`, which has a minimum. Measured confirmation
> and the resulting design are in
> [`adr-0001-coil-technology.md`](adr-0001-coil-technology.md); the corrected
> answer is 21 turns of 0.30 mm trace in **12–16 transposed layers**, and a
> plain parallel stack fails. The table is left below as the record of what the
> broken model said.

At 32 turns and 0.80 mm trace, **per the defective 1/N model**:

| Layers | R_ac | Q | k·Q | Loss | Per pad | vs k·Q ≥ 49 |
|---|---|---|---|---|---|---|
| 1 | 3.27 Ω | 29 | 13.5 | 412 W | 206 W | fails |
| 2 | 1.64 Ω | 59 | 27.1 | 214 W | 107 W | fails |
| 4 | 0.82 Ω | 117 | 54.1 | 109 W | 54 W | **passes**, 1.10× |
| **6** | **0.55 Ω** | **176** | **81.2** | **73 W** | **36 W** | **passes, 1.66×** |
| 8 | 0.41 Ω | 235 | 108.3 | 55 W | 27 W | passes, 2.21× |

**Six layers was the design point, and it was wrong** — with the corrected
model, six plain layers sit past the optimum and are *worse* than four. See
ADR-0001.

### The design point, across the full misalignment envelope

**32 turns · 0.80 mm trace · 0.28 mm clearance · 6 layers in parallel · 4 oz ·
102 × 203 mm outer**, giving L = 180 µH and M = 82.9 µH against the 80.9 µH
required.

| Gap | Lateral | Tilt | k | k·Q | Loss |
|---|---|---|---|---|---|
| 5 mm | 0 | 0° | 0.799 | 141 | 42 W |
| 10 mm | 10 mm | 3° | 0.618 | 109 | 55 W |
| 20 mm | 0 | 0° | 0.461 | 81 | 73 W |
| **20 mm** | **10 mm** | **0°** | **0.437** | **77.0** | **77 W** |

**Worst case k·Q = 77 against a requirement of 49 — a 1.57× margin.**

### The thermal problem got harder, not easier

38 W leaving a 102 × 203 mm pad is **1858 W/m²**, against 764 W/m² for the same
allowance on the 300 mm circular pad. The rectangular pad is 3.6× smaller in
area, so the same watts are a substantially harder extraction. `MEC-004`'s
**temperature limit is the binding form of that requirement**, not its per-pad
watt allocation — and the watt figure should be re-derived from the temperature
once the ferrite and cold-plate stack is modelled.

### What is still open, and what now matters most

1. ~~Inter-layer proximity is the largest modelling uncertainty.~~
   **RESOLVED, against us.** Published measurement says two parallel layers cut
   resistance by 15.9%, not 50%. The uncertainty flagged here was the right one
   and the answer was the unfavourable one. See ADR-0001.
2. Ferrite backing, cold-plate eddy loss and seawater in the gap remain
   unmodelled and all push the wrong way.
3. Kuhn–Ibrahim is still outside its fitted trace width — but at 0.80 mm the AC
   correction is only 6%, so the error it carries is now small enough not to
   matter much. The single-layer circular case, where the correction was 77%,
   was where that caveat really bit.

### Why the earlier conclusion was wrong

Worth recording, because the failure mode is general. The single-layer circular
analysis was correct as far as it went. The error was scope: one configuration
was tested and the conclusion was written about a whole conductor technology.
Three cheap levers went unexamined — layers, trace width, and the interaction
between them — and the first of them turns a 190 W failure into a 73 W pass.

`MEC-001` itself needs no change. It was written against k·Q and pad
dissipation rather than against a coil technology, precisely so the decision
would be settled by arithmetic. A six-layer etched coil meets it. **That is the
requirement working correctly, and the analysis around it that failed.**

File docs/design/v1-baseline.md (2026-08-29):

# v1 baseline — the Mako 2.0 wireless charger as documented

Source: `docs/reference/source/mako-charging-white-paper.pdf`, plus the two
firmware repositories archived under `docs/reference/source/fw-v1/`.

This document is the **as-documented** record of v1 and a review of it. It is
not a design for v2. Its job is to establish what exists, which numbers are
trustworthy, and which of them will not survive contact with the 3 kW target —
so that the v2 requirements are written against reality rather than against the
white paper's claims.

Everything in *Findings* was derived from the primary sources: the vendor
datasheets in `docs/reference/manifest.yaml` and the firmware source itself.

## 1. Top-level intent

| Parameter | Value | Source |
|---|---|---|
| Max power transfer | 3 kW | white paper p.1 |
| Input bus | 400 VDC | white paper p.1 |
| Vehicle battery | 8 kWh | white paper p.1 |
| Target charge time | 2.6 h | white paper p.1 |
| Coupling | magnetic resonant, air gap | white paper p.1 |
| Drive frequency band | 80–120 kHz, 85 kHz nominal | white paper p.3 |

The 2.6 h figure is consistent: 8 kWh ÷ 3 kW = 2.67 h at 100% efficiency, so it
is a *floor*, and it assumes the charger holds full power for the whole charge.
A real CC/CV profile tapers, so 2.6 h is not achievable end-to-end. **v2 should
state charge time against a defined SoC window and efficiency, not as 8/3.**

## 2. Architecture as built

Three boards, two of them on one PCB (`RXTX`):

```
Leviathan 400 V ─► HVLV (dual active bridge) ─► TX H-bridge ─► TX coil
                                                                 ) )  air gap
                       Mako battery ◄─ RX rectifier ◄─ RX coil ◄─
```

* **HVLV** — bi-directional dual active bridge, planar transformer, phase-shift
  controlled by an STM32H723ZGT6 using TIM1/TIM8.
  HV bridge `IPB60R120` CoolMOS; LV bridge `BSC190N` OptiMOS, two paralleled per
  branch. Isolation set: `UCC1414` (gate-drive power), `ISO7740` (PWM),
  `ISO224` (analog), `UCC33420` (digital power). Gate drive `UCC27741`.
  Aux rails from `TPSM560`.
* **TX** — high-voltage GaN H-bridge, `LMG2610`, 80–120 kHz square wave into a
  series-resonant tank. Current-sense emulation → `OPA2328` → STM32H723ZGT6 ADC.
  Aux rails from `TPSM540`. The LMG2610 is also the star ground point between
  power and analog ground.
* **RX** — 12 × `MURSDA860` in a bridge rectifier (3 paralleled per leg), 11 µF
  bulk, `TMCS1133` isolated Hall current sense, STM32G431 compute.
* **Coils** — PCB-etched spirals, 5 mm trace width, 12 µH, 0.8 Ω series, Q = 12,
  ferrite backing with a cooling path underneath.

## 3. Findings

### F1 — The TX power stage is specified ~40× below the power target *(blocking)*

The white paper states the LMG2610 is "rated for a 600V bus and drain current of
6.4A". The datasheet (SNOSDE2A, `docs/reference/lmg2610-SNOSDE2A.pdf`) says:

* 650 V, not 600 V.
* **6.4 A is the low-side absolute-maximum *peak* drain current. The high-side
  abs-max peak is 4 A.** Neither is a continuous rating; both are abs-max, i.e.
  the value beyond which damage is permitted, not a design point.
* The device is "intended for **< 75-W** active-clamp flyback converters".
* The 170 mΩ low-side / 248 mΩ high-side asymmetry is *deliberate* — "optimized
  for ACF operating conditions". A 50%-duty resonant H-bridge cannot use it.

Against the 3 kW target, using first-harmonic approximation for a square-wave
driven series-resonant tank at resonance:

| Quantity | Value |
|---|---|
| DC input current, 3 kW / 400 V | 7.50 A |
| Fundamental RMS of the 400 V square wave, `2√2·V/π` | 360 V |
| Tank current, 3000 W / 360 V | **8.33 A RMS** |
| Tank current peak | **11.8 A peak** |
| Per-FET RMS (≈50% conduction) | 5.89 A |

So the high-side FET would see 11.8 A peak against a 4 A absolute maximum —
**2.9× over abs-max** — and the low-side 11.8 A against 6.4 A, **1.8× over**.

Thermally it is worse. Conduction loss alone, ignoring all switching loss:

| | RDS(on) | I²R at 5.89 A RMS |
|---|---|---|
| Low-side | 170 mΩ | 5.90 W |
| High-side | 248 mΩ | 8.61 W |
| **Per package** | | **14.5 W** |

With RθJA = 25.3 °C/W that is a 367 °C rise, against TJ(max) = 150 °C. Even
bonded to a perfect heatsink through RθJC(bot) = 1.22 °C/W, 14.5 W in a 9×7 mm
QFN is not a package you can cool — and the current-sense emulation function
requires the low-side thermal pad to be tied to power ground, which constrains
the heatsinking further.

**This is not a margin problem. The part cannot reach the target and would fail
on the first attempt at full power.** It is consistent with the white paper's
own evidence: p.7 reports bench results for resonance *tracking* only, and
never reports a power figure.

Replacement class: a 650 V GaN FET around 30 mΩ with an integrated driver —
e.g. TI `LMG3522R030`/`LMG3526R030` (650 V, 30 mΩ, top-cooled 12×12 VQFN, TI's
own evaluation board runs 3.6 kW). At 30 mΩ the same 5.89 A RMS gives 1.04 W per
FET instead of 5.9–8.6 W. Confirm in sourcing; this is a class, not yet a choice.

### F2 — Several part numbers do not resolve to orderable parts

| White paper | Resolves to | Note |
|---|---|---|
| `TPSM540` and `TPSM560` (both used) | `TPSM560R6` (600 mA) or `TPSM5601R5` (1.5 A) | Neither paper name is a real part. 600 mA vs 1.5 A changes the aux-rail budget. |
| `UCC1414` | `UCC14240-Q1` (2.0 W isolated gate-drive bias) | |
| `UCC27741`, "rating of 650V" | `UCC27714`, rated **600 V** | Digits transposed *and* the voltage is wrong. Direct margin impact on a 400 V bus. |
| `MURSDA860`, described as "schottky" | closest real family `MUR860` / `MURS` — **ultrafast recovery, not Schottky** | See F3. |
| `IPB60R120` | `IPB60R120C7` (600 V, 120 mΩ, 19 A) | 600 V on a 400 V bus is 1.5× — thin for a bridge with leakage ringing. |
| `BSC190N` | `BSC190N15NS3-G` (150 V, 19 mΩ, 50 A) | 150 V bounds the LV bus. See F5. |

`LMG2610`, `OPA2328`, `TMCS1133`, `ISO7740`, `ISO224`, `UCC33420`,
`STM32H723ZGT6` and `STM32G431` all resolve correctly.

### F3 — The RX rectifier is not a Schottky bridge

`MUR` is an ultrafast *PN* recovery family, not Schottky, and silicon Schottky
does not exist at 600 V — above roughly 200 V, "Schottky" means SiC. So the v1
bridge has both a ~1.7 V forward drop *and* reverse-recovery charge, at
85–120 kHz, which is exactly what the paper says it wanted to avoid.

At the paper's own 6 A load, two diodes in series conducting: 2 × 1.7 V × 6 A =
**20.4 W** in the bridge. This is the thermal problem p.5 gestures at, quantified.

A 650 V SiC Schottky (e.g. Wolfspeed C3D/C6D, onsemi FFSH) has essentially zero
reverse recovery, which removes the switching-loss term entirely. Forward drop
is comparable, so the win is in recovery and in EMI, not in conduction. **v2
should either move to SiC Schottky or, better, evaluate synchronous rectification** —
at 3 kW the diode bridge is the largest single loss term outside the coils.

### F4 — The coil numbers are internally inconsistent, and the coils dominate loss

12 µH with 0.8 Ω series resistance gives:

| f | X_L | Q = X_L/R | C for resonance |
|---|---|---|---|
| 85 kHz | 6.41 Ω | **8.0** | 292 nF |
| 100 kHz | 7.54 Ω | 9.4 | 211 nF |
| 120 kHz | 9.05 Ω | 11.3 | 147 nF |

The stated Q of 12 corresponds to ≈127 kHz, not to the stated 85 kHz nominal.
Either Q was measured at the top of the band, or R is lower than 0.8 Ω, or the
numbers come from different builds. **One of these three numbers is wrong and
v2 must measure all three on one physical coil before anything is designed
around them.**

The loss is the bigger issue. At the 8.33 A RMS that 3 kW demands:

* I²R per coil = 8.33² × 0.8 = **55.5 W**
* Both coils = **111 W**, i.e. ~3.7% of 3 kW *in the coils alone*

55 W spread over a PCB spiral, cooled only through the ferrite backing, is the
hardest thermal problem in the system — considerably harder than the white paper
implies when it calls PCB-coil thermals a "drawback". Note also that 0.8 Ω is
presumably a DC measurement; at 85 kHz, skin and proximity effect in a 5 mm
copper trace will make the AC resistance higher, so 55 W is a floor.

**This is the finding most likely to force an architecture change** — wider or
thicker copper, more layers in parallel, a lower tank current via a higher bus
voltage, or a return to Litz.

### F5 — The LV bus voltage is undefined, and the firmware contradicts the FETs

The white paper never states the Mako battery voltage. The HVLV firmware sets
`v_ref = 250.0f` — but the LV bridge uses 150 V-rated `BSC190N15NS3`. If the LV
bus really were 250 V the LV FETs would be destroyed at rest.

Most likely `v_ref` is one of the `FILL THIS OUT LATER` placeholders (it is
declared among them) rather than a real setpoint. But the LV bus voltage sets
the LV bridge current, the transformer turns ratio, and the entire LV thermal
design. **This is the single biggest open question in the v1 record and it
blocks the DAB architecture.** It must be answered by the human before any HVLV
work starts.
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

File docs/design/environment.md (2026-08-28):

# Environmental envelope

Chunk **R2**. The dock electronics sit in an enclosure on the **open deck** of a
surface vessel operating worldwide (vision interview, 2026-08-28).

## The maximum

IEC 60945 is the maritime navigation and radiocommunication equipment standard,
and it derives its exposed-equipment maximum this way:

| Term | Value |
|---|---|
| Maximum expected air temperature at sea | **+32 °C** |
| Maximum solar gain at sea | **+23 °C** |
| **Total design maximum** | **+55 °C** |

That derivation is what makes +55 °C the right number rather than an arbitrary
round figure: it is an air temperature plus a solar allowance, and the solar
allowance is the larger part of it. An open-deck enclosure gets both.

**Design maximum ambient: +55 °C.** This is the number `SYS-016` carries and
the boundary condition the thermal work in `M3` runs against.

## The minimum

IEC 60945 splits equipment into protected (Class A) and exposed (Class B), with
Class B carrying the lower cold limit. **−25 °C** is the figure generally cited
for the exposed class, and it is what this project designs to — but see the
caveat below.

## What could not be verified

**The IEC 60945 standard itself is paywalled** and the secondary sources that
describe it do not carry the per-class numbers consistently. The +32/+23/+55 °C
derivation above is well attested across independent sources; the −25 °C cold
limit and the exact clause references are not, at the level of confidence this
project's rules require.

Recorded as blocked in `docs/reference/manifest.yaml`. **A purchased copy is
needed before `SYS-016` can be cited as compliant with IEC 60945** rather than
merely consistent with it. The +55 °C maximum is safe to design against now; the
cold limit should be confirmed before anything is qualified against it.

Two further sources worth having, neither yet fetched: **IACS UR E10** (type
testing for shipboard equipment) and the classification-society rules from DNV
and Lloyd's Register, which set ambient temperatures per location class and may
be more stringent than IEC 60945 for equipment in an unconditioned space.

## Why the maximum bites harder than it looks

The thermal budget is not "55 °C ambient, dissipate 300 W". It is 55 °C
ambient, **conduction only**, no pumped coolant and no forced air — so the
temperature rise from the coil conductor through the ferrite, the interface and
the cold plate to the structure, and from the structure to the sea, all has to
fit in the margin between +55 °C and the conductor's 100 °C limit in `MEC-004`.

**That is a 45 °C budget for the whole chain.** It is the reason `MEC-001`'s
coil loss allowance is 120 W and not a looser number, and it is why the etched
spiral's predicted 190 W is disqualifying rather than merely disappointing.

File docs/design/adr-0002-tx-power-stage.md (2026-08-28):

# ADR-0002 — TX power stage device

**Status:** Accepted for the architecture; the alternate is not yet fully verified.
**Date:** 2026-08-28
**Chunk:** E1

## Context

`ELE-005` requires each transmitter bridge switch to carry 17 A continuous and
24 A repetitive peak; `ELE-006` requires at least 650 V with an 80% derating
ceiling; `ELE-001` allows the whole four-switch bridge 25 W at 3 kW, where each
device sees 5.89 A RMS.

The v1 device, TI **LMG2610**, is disqualified by finding F1: it is a 650 V GaN
half bridge specified for **under 75 W active-clamp flyback**, whose 6.4 A and
4 A drain figures are absolute-maximum *peaks*, and whose 170/248 mΩ asymmetric
on-resistances are deliberately optimised for flyback duty and cannot be
balanced in a 50%-duty bridge.

A further constraint the v1 review surfaced: gate-loop parasitics were named in
the white paper as the reason the LMG2610 was chosen in the first place. Whatever
replaces it should keep the driver inside the package rather than reintroduce
the loop.
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

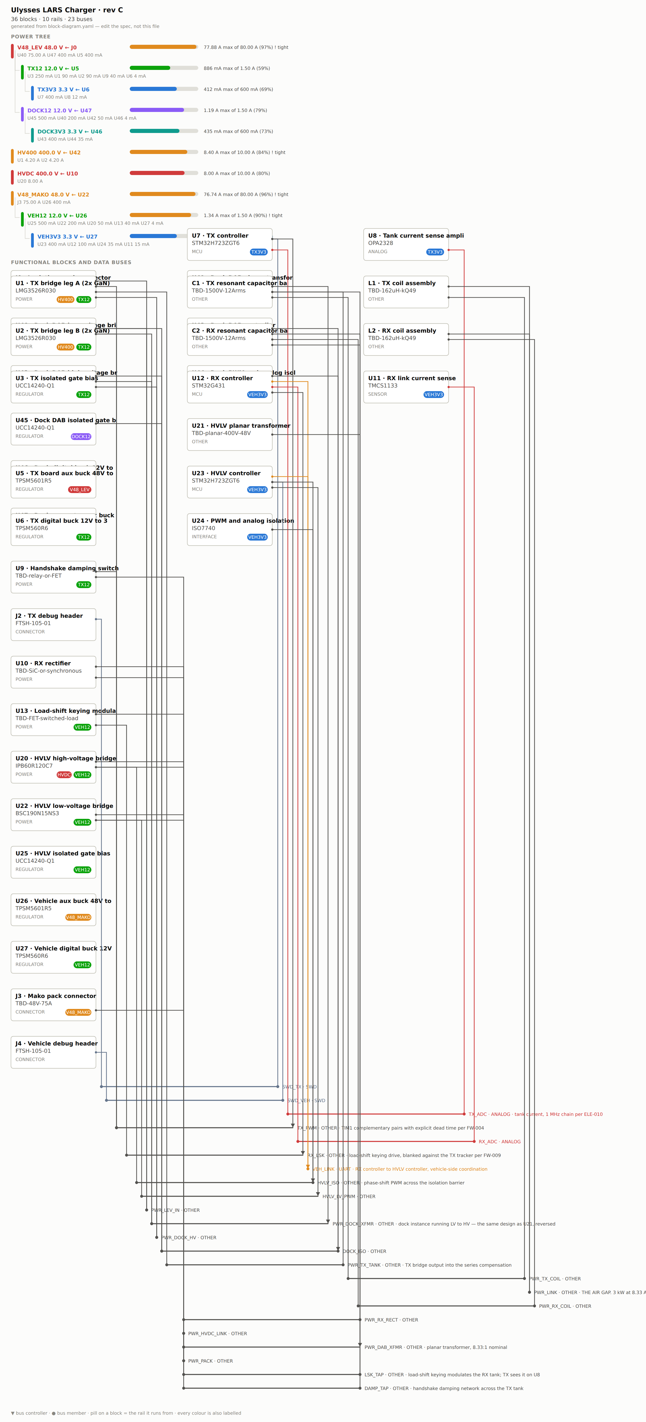
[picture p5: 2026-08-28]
docs/design/block-diagram.png

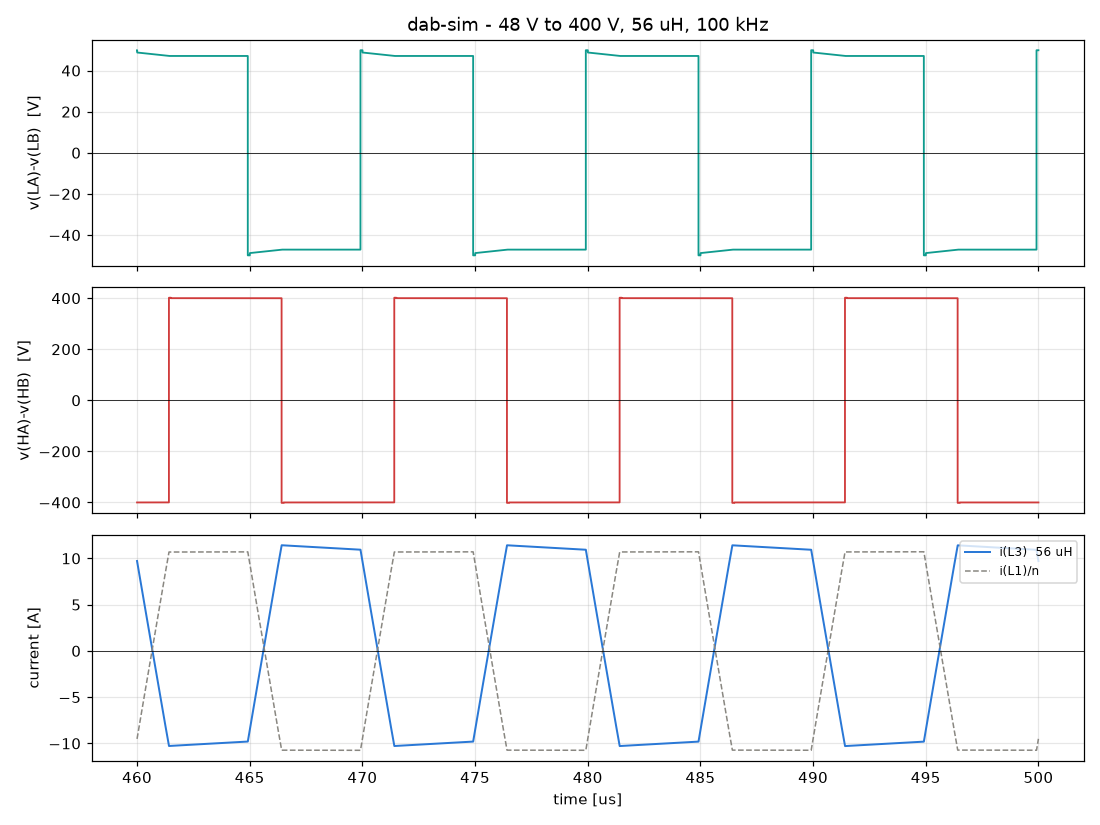
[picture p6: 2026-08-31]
sim/kicad/dab-waveforms.png

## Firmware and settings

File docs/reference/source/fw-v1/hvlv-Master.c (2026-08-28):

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
/* Includes ------------------------------------------------------------------*/
#include "main.h"

/* USER CODE BEGIN Includes */

#include <stdio.h>
#include <string.h>
#include <math.h>

/* USER CODE END Includes */

/* USER CODE BEGIN PTD */

typedef struct {
    float Kp;
    float Ki;
    float integrator;
    float out_min;
    float out_max;
} PI_Controller_t;

/* USER CODE END PTD */

ADC_HandleTypeDef hadc1;
ADC_HandleTypeDef hadc2;

TIM_HandleTypeDef htim1;
TIM_HandleTypeDef htim6;
TIM_HandleTypeDef htim8;

/* USER CODE BEGIN PV */

#define CURRENT_SENSOR_MV_PER_A   100.0f   // FILL THIS OUT LATER
#define VOLTAGE_SENSE_RATIO       0.005f   // FILL THIS OUT LATER
#define ARR_PHASE_MAX             200u     // FILL THIS OUT LATER
#define CONTROL_TS                50e-6f   // FILL THIS OUT LATER

//Find out Kp and Ki in experimental testing

static PI_Controller_t currentPI = { .Kp = 0.02f, .Ki = 40.0f,  .integrator = 0.0f, .out_min = 0.0f, .out_max = 0.5f }; //FILL THIS OUT LATER
static PI_Controller_t voltagePI = { .Kp = 0.5f,  .Ki = 5.0f,   .integrator = 0.0f, .out_min = 0.0f, .out_max = 20.0f }; // FILL THIS OUT LATER

volatile uint8_t cvcc = 0;          // 0 = CC, 1 = CV
volatile float v_ref = 250.0f;      // FILL THIS OUT LATER
volatile float i_ref_cc = 15.0f;    // FILL THIS OUT LATER
volatile uint32_t phaseShiftPulse = 0;



/* USER CODE END PV */

void SystemClock_Config(void);
void PeriphCommonClock_Config(void);
static void MPU_Config(void);
static void MX_GPIO_Init(void);
static void MX_TIM1_Init(void);
static void MX_TIM8_Init(void);
static void MX_ADC1_Init(void);
static void MX_ADC2_Init(void);
static void MX_TIM6_Init(void);
/* USER CODE BEGIN 0 */

uint32_t rawToMV(uint32_t raw);

static float PI_Update(PI_Controller_t *pi, float error, float Ts);

static void ControlLoop_Update(void);

/* USER CODE END 0 */

/**
  * @brief  The application entry point.
  * @retval int
  */
int main(void)
{

  /* MPU Configuration--------------------------------------------------------*/
  MPU_Config();

  /* MCU Configuration--------------------------------------------------------*/

  /* Reset of all peripherals, Initializes the Flash interface and the Systick. */
  HAL_Init();

  /* Configure the system clock */
  SystemClock_Config();

  /* Configure the peripherals common clocks */
  PeriphCommonClock_Config();

  /* Initialize all configured peripherals */
  MX_GPIO_Init();
  MX_TIM1_Init();
  MX_TIM8_Init();
  MX_ADC1_Init();
  MX_ADC2_Init();
  MX_TIM6_Init();
  /* USER CODE BEGIN 2 */

  HAL_TIM_PWM_Start(&htim1,TIM_CHANNEL_1);
  HAL_TIMEx_PWMN_Start(&htim1,TIM_CHANNEL_1);
  HAL_TIM_PWM_Start(&htim1,TIM_CHANNEL_2);
  HAL_TIMEx_PWMN_Start(&htim1,TIM_CHANNEL_2);

  HAL_TIM_PWM_Start(&htim1, TIM_CHANNEL_3);

  HAL_TIM_PWM_Start(&htim8,TIM_CHANNEL_1);
  HAL_TIMEx_PWMN_Start(&htim8,TIM_CHANNEL_1);
  HAL_TIM_PWM_Start(&htim8,TIM_CHANNEL_2);
  HAL_TIMEx_PWMN_Start(&htim8,TIM_CHANNEL_2);
  /* USER CODE END 2 */

  /* Infinite loop */
  /* USER CODE BEGIN WHILE */


  HAL_ADCEx_Calibration_Start(&hadc1, ADC_CALIB_OFFSET, ADC_SINGLE_ENDED);
  HAL_ADCEx_Calibration_Start(&hadc2, ADC_CALIB_OFFSET, ADC_SINGLE_ENDED);
  HAL_TIM_Base_Start_IT(&htim6);   /* <-- starts the control loop interrupt */


  while (1)
  {

    /* USER CODE END WHILE */

    /* USER CODE BEGIN 3 */


  }
  /* USER CODE END 3 */
}

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
/* USER CODE BEGIN 4 */

void HAL_TIM_PeriodElapsedCallback(TIM_HandleTypeDef *htim)
{
    if (htim->Instance == TIM6) {
        ControlLoop_Update();
    }
}

uint32_t rawToMV(uint32_t raw) //converts base ADC values into comprehensible voltage outputs
{
    return (raw * 3300UL) / 65535UL;
}

static float PI_Update(PI_Controller_t *pi, float error, float Ts)
{
    float p_term = pi->Kp * error;

    pi->integrator += pi->Ki * error * Ts;
    if (pi->integrator > pi->out_max) pi->integrator = pi->out_max;
    if (pi->integrator < pi->out_min) pi->integrator = pi->out_min;  // anti-windup clamp

    float output = p_term + pi->integrator;
    if (output > pi->out_max) output = pi->out_max;
    if (output < pi->out_min) output = pi->out_min;
    return output;
}

static void ControlLoop_Update(void)
{
    uint32_t current_read = 0, voltage_read = 0;
    float i_threshold = 0; // FILL THIS OUT LATER


    HAL_ADC_Start(&hadc1);
    if (HAL_ADC_PollForConversion(&hadc1, 1) == HAL_OK) {
        current_read = rawToMV(HAL_ADC_GetValue(&hadc1));
    }

    HAL_ADC_Start(&hadc2);
    if (HAL_ADC_PollForConversion(&hadc2, 1) == HAL_OK) {
        voltage_read = rawToMV(HAL_ADC_GetValue(&hadc2));
    }

    float i_batt = current_read / CURRENT_SENSOR_MV_PER_A;
    float v_batt = (voltage_read / 1000.0f) / VOLTAGE_SENSE_RATIO;

    /* CC -> CV handoff */
    if (!cvcc && v_batt >= v_ref) {
        cvcc = 1;
    }

    /* Outer loop (CV only) or fixed setpoint (CC) */
    float i_setpoint;
    if (!cvcc) {
        i_setpoint = i_ref_cc;
    } else {
        float v_error = v_ref - v_batt;
        i_setpoint = PI_Update(&voltagePI, v_error, CONTROL_TS);
    }

    /* Inner current loop — always runs, in both modes */
    float i_error = i_setpoint - i_batt;
    float D = PI_Update(&currentPI, i_error, CONTROL_TS);

    phaseShiftPulse = (uint32_t)(D * ARR_PHASE_MAX);
    if (i_batt < i_threshold) {
    	TIM1->CCR3 = phaseShiftPulse;
    }

}

/* USER CODE END 4 */

 /* MPU Configuration */

void MPU_Config(void)
{
  MPU_Region_InitTypeDef MPU_InitStruct = {0};

  /* Disables the MPU */
  HAL_MPU_Disable();

  /** Initializes and configures the Region and the memory to be protected
  */
  MPU_InitStruct.Enable = MPU_REGION_ENABLE;
  MPU_InitStruct.Number = MPU_REGION_NUMBER0;
  MPU_InitStruct.BaseAddress = 0x0;
  MPU_InitStruct.Size = MPU_REGION_SIZE_4GB;
  MPU_InitStruct.SubRegionDisable = 0x87;
  MPU_InitStruct.TypeExtField = MPU_TEX_LEVEL0;
  MPU_InitStruct.AccessPermission = MPU_REGION_NO_ACCESS;
  MPU_InitStruct.DisableExec = MPU_INSTRUCTION_ACCESS_DISABLE;
  MPU_InitStruct.IsShareable = MPU_ACCESS_SHAREABLE;
  MPU_InitStruct.IsCacheable = MPU_ACCESS_NOT_CACHEABLE;
  MPU_InitStruct.IsBufferable = MPU_ACCESS_NOT_BUFFERABLE;

  HAL_MPU_ConfigRegion(&MPU_InitStruct);
  /* Enables the MPU */
  HAL_MPU_Enable(MPU_PRIVILEGED_DEFAULT);

}

/**
  * @brief  This function is executed in case of error occurrence.
  * @retval None
  */
void Error_Handler(void)
{
  /* USER CODE BEGIN Error_Handler_Debug */
  /* User can add his own implementation to report the HAL error return state */
  __disable_irq();
  while (1)
  {
  }
  /* USER CODE END Error_Handler_Debug */
}
#ifdef USE_FULL_ASSERT
/**
  * @brief  Reports the name of the source file and the source line number
  *         where the assert_param error has occurred.
  * @param  file: pointer to the source file name
  * @param  line: assert_param error line source number
  * @retval None
  */
void assert_failed(uint8_t *file, uint32_t line)
{
  /* USER CODE BEGIN 6 */
  /* User can add his own implementation to report the file name and line number,
     ex: printf("Wrong parameters value: file %s on line %d\r\n", file, line) */
  /* USER CODE END 6 */
}
#endif /* USE_FULL_ASSERT */

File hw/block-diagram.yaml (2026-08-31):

# Electrical block diagram — the architecture agreement, settled before schematic capture.
#
#   block-diagram                 # -> hw/block-diagram.drawio + docs/design/block-diagram.svg
#   block-diagram --check         # validate only; exit 1 on a broken tree or an over-budget rail
#   block-diagram --summary       # power budget per rail, no files written
#
# STATUS: PROVISIONAL. Chunk E1B in plan.yaml depends on E1 (part selection) and
# M2 (magnetics), neither of which has run. The architecture and the tree shape
# are agreed here; the currents marked (est) below are engineering estimates and
# must be replaced with datasheet figures before E1B closes. Every part whose
# datasheet has not been fetched is recorded blocked in
# docs/reference/manifest.yaml.
#
# ARCHITECTURE, rev C: one bidirectional converter design instantiated TWICE
# (SYS-015). The dock instance runs LV->HV, stepping the 48 V Leviathan pack up
# to the 400 V bus; the vehicle instance runs HV->LV, stepping the rectified
# link down to the 48 V Mako pack. Both packs are 48 V nominal, so one
# low-voltage specification covers both ends.
#
# Because the dock has a 48 V pack of its own, the transmitter's auxiliary
# rails come from 48 V through the same buck used on the vehicle. The 700 V
# offline flyback that rev B needed disappears entirely.
#
# The power tree drawn here is the CHARGING-MODE tree. The vehicle pack also
# back-feeds the vehicle auxiliary rails when no charge is in progress, which the
# single-source tree below cannot express; see docs/design/in-band-comms.md for
# why that path matters (the receiver has to be awake to answer a handshake).

project: Ulysses LARS Charger
revision: C

# --------------------------------------------------------------------------
# Power tree.
#
# The coils are the boundary of the wired tree: HVDC has no `from` because its
# energy arrives across the magnetic link, not along a conductor.
# --------------------------------------------------------------------------
rails:

  # ---- dock side ----
  - id: V48_LEV
    voltage: 48.0
    source: J0
    max_current_a: 80.0
    notes: >-
      Leviathan pack, 48 V nominal — the same specification as the Mako pack,
      which is what lets one converter design serve both ends. Carries 62.5 A at
      3 kW and 75 A at the bottom of the SYS-003 window.

  - id: HV400
    voltage: 400.0
    source: U42
    max_current_a: 10.0
    notes: >-
      Dock link bus, made by the Leviathan-side converter running LV->HV.
      3 kW at 400 V is 7.5 A. No `from` — the DAB is galvanically isolated and
      U40's declared draw on V48_LEV is the referred current.

  - id: TX12
    voltage: 12.0
    from: V48_LEV
    source: U5
    max_current_a: 1.5
    notes: >-
      Gate-drive and isolated-bias input rail, taken straight from the 48 V
      Leviathan pack. Sized at 1.5 A, not the 600 mA a TPSM560R6 gives: the
      first pass of this budget came out over on a 600 mA part, which is the
      concrete form of the v1 white paper's confusion between "TPSM540" and
      "TPSM560".

  - id: TX3V3
    voltage: 3.3
    from: TX12
    source: U6
    max_current_a: 0.6
    notes: >-
      TX BOARD digital and analog domain. Generated by a buck, not an LDO:
      400 mA dropped from 12 V to 3.3 V is 3.5 W of heat on a board that already
      has nowhere to put any.

  - id: DOCK12
    voltage: 12.0
    from: V48_LEV
    source: U47
    max_current_a: 1.5
    notes: >-
      Leviathan-side CONVERTER BOARD auxiliary rail, separate from the
      transmitter's. The dock is two boards, so it is two aux trees; the
      transmitter takes 48 V over the dock harness alongside the 400 V link.

  - id: DOCK3V3
    voltage: 3.3
    from: DOCK12
    source: U46
    max_current_a: 0.6

  # ---- vehicle side ----
  - id: HVDC
    voltage: 400.0
    source: U10
    max_current_a: 10.0
    notes: >-
      Rectified link output. No `from` — this rail is fed across the coils, so
      it is where the wired tree restarts on the vehicle.

  - id: V48_MAKO
    voltage: 48.0
    source: U22
    max_current_a: 80.0
    notes: >-
      Pack rail. 3 kW at 48 V is 62.5 A, and 75 A at the bottom of the SYS-003
      window; 80 A is the continuous rating the LV bridge and its copper are
      designed to (ELE-008). No `from` — the DAB is galvanically isolated, and
      U20's declared draw on HVDC is the referred current.

  - id: VEH12
    voltage: 12.0
    from: V48_MAKO
    source: U26
    max_current_a: 1.5
    notes: vehicle gate-drive and isolated-bias input rail, RX and HVLV together

  - id: VEH3V3
    voltage: 3.3
    from: VEH12
    source: U27
    max_current_a: 0.8
    notes: vehicle digital and analog domain, RX and HVLV together
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

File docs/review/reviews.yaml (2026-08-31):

# Human review sign-off ledger — written by `review-gate`.
#
# A stage is done when its review here says `approved` and no artefact
# has changed since. The digests are how staleness is detected; do not
# hand-edit them. To record a decision:
#
#   review-gate sign <id> --approve --by <name> --note "what they said"
#   review-gate sign <id> --changes "what they want different"
reviews:
- id: vision
  title: Vision, scope and the coil decision
  stage: vision
  summary: 'Re-opened 2026-08-31 after the scope change. Scope is now the charger ELECTRONICS
    plus a test packaging (VIS-013): integration, the deck fixture and the handling belong
    to the mechanical team. The three locating concepts you were previously asked to choose
    between are withdrawn with the fixture, and the locating scheme is set to pins (VIS-005).
    What replaces them is one concept — a bench rig that holds the coil pair at the SYS-006
    envelope so the magnetics can be measured. Read the scope line and the pin decision first;
    those are the two things this review is really asking about. Note what the scope cut did
    NOT do: MEC-009, the surface area that cools the pad, was re-aimed as an interface requirement
    on whoever builds the mount rather than deleted along with the bracket. The coil itself
    is unchanged and still settled in ADR-0001 as a 16-layer transposed etched PCB.'
  questions:
  - Is the scope line right — electronics plus a test rig, with integration and the fixture
    going to the mechanical team?
  - 'Pins: two dowels, hole and slot. Is there anything about the real fixture that would
    make a different interface better?'
  - Is 8-14 mm of gap and 5 mm of offset what the fixture can actually hold? This is our assumption
    about someone else's part and it is the weakest thing in the document.
  - 16 layers at 4 oz is a 64 oz heavy-copper board. Still acceptable, or should I re-open
    Litz?
  artifacts:
  - path: docs/design/adr-0001-coil-technology.md
    sha256: 99037ce2843385d6
  - path: docs/design/vision-gallery.md
    sha256: 2074f06e7b431182
  - path: docs/design/vision.md
    sha256: 8dd4f285e744cfde
  - path: docs/design/vision/manifest.json
    sha256: c4a9b3d1c4a0b75c
  - path: docs/design/vision/test_packaging/iso.svg
    sha256: 8840323fe2029dbf
  - path: docs/design/vision/test_packaging/view-front.png
    sha256: e816bf71ceadfffc
  - path: docs/design/vision/test_packaging/view-hero.png
    sha256: 66d571c1288202ab
  - path: docs/design/vision/test_packaging/view-top.png
    sha256: 5763433d732c2def
  requested: '2026-08-31'
  requested_commit: 33178dc
  status: requested
  packet: docs/review/vision.md
  history:
  - 'on': '2026-08-31'
    action: requested
    commit: 01181dd
    questions:
    - Which locating approach — cone/vee/flat, tapered rails, or perimeter nest?
    - 16 layers at 4 oz is a 64 oz heavy-copper board. Is that acceptable, or should I re-open
      Litz?
    summary: Scope is the charging system only. Belly dock, no actuator, charging on deck
      in a locating bracket — all decided. The three concepts below differ on how the two
      pads locate to each other, which is the remaining mechanical decision. The coil is settled
      in ADR-0001 as a 16-layer transposed etched PCB, and the write-up says plainly where
      I got it wrong twice before landing there.
    added:
    - docs/design/adr-0001-coil-technology.md
    - docs/design/vision.md
    - docs/design/vision/locate_cone_vee/iso.svg
    - docs/design/vision/locate_cone_vee/view-front.png
    - docs/design/vision/locate_cone_vee/view-hero.png
    - docs/design/vision/locate_cone_vee/view-top.png
    - docs/design/vision/locate_nest/iso.svg
    - docs/design/vision/locate_nest/view-front.png
    - docs/design/vision/locate_nest/view-hero.png
    - docs/design/vision/locate_nest/view-top.png
    - docs/design/vision/locate_tapered_rails/iso.svg
    - docs/design/vision/locate_tapered_rails/view-front.png
    - docs/design/vision/locate_tapered_rails/view-hero.png
    - docs/design/vision/locate_tapered_rails/view-top.png
    - docs/design/vision/manifest.json
  - 'on': '2026-08-31'
    action: requested
    commit: 33178dc
    questions:
    - Is the scope line right — electronics plus a test rig, with integration and the fixture
      going to the mechanical team?
    - 'Pins: two dowels, hole and slot. Is there anything about the real fixture that would
      make a different interface better?'
    - Is 8-14 mm of gap and 5 mm of offset what the fixture can actually hold? This is our
      assumption about someone else's part and it is the weakest thing in the document.
    - 16 layers at 4 oz is a 64 oz heavy-copper board. Still acceptable, or should I re-open
      Litz?
    summary: 'Re-opened 2026-08-31 after the scope change. Scope is now the charger ELECTRONICS
      plus a test packaging (VIS-013): integration, the deck fixture and the handling belong
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

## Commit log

2026-08-28 Scaffold MakeHardware project and capture v1 charger baseline
    Scaffolds the repo from the MakeHardware project template (plan.yaml,
    requirements/, hw/, cad/, concepts/, sim/, docs/, strictdoc.toml, CLAUDE.md)
    for the Ulysses LARS Charger, and records the v1 research.
    Research captured:
    - docs/reference/source/ — the Mako charging white paper (PDF + extracted
    text) and the v1 TXRX/HVLV firmware, pinned to their source commits.
    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
2026-08-28 Vision: v2 intent, link budget, and the two coil concepts
    Captures the vision interview as VIS-001..VIS-010 and works the four numbers
    the white paper never stated into an analysis that decides the architecture.
    The interview supplied: a 48 V / 33 Ah pack that grows in capacity but not
    voltage, a sub-20 mm well-aligned dock (k ~ 0.5), a 3 kW target the
    requirements may move, and conduction-to-chassis cooling with no pumped
    coolant.
    sim/link-budget/link_budget.py works those through the closed-form
    series-series relations. Two results decide v2:
    - The v1 12 uH coil is 13x too small for a 3 kW link at 400 V. At resonance
    with 360 V fundamental both ends it wants to transfer 40 kW at 112 A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
2026-08-28 Plan: 21 chunks across five disciplines, 13 sessions on the critical path
    Coil bench characterisation (M1) sits on the critical path immediately after
    requirements, because the whole architecture argument rests on a coil quality
    factor nobody in the programme has measured, and the v1 figures are internally
    inconsistent -- a stated Q of 12 implies 127 kHz, not the stated 85 kHz
    nominal.
    Critical path: V1 -> R1 -> M1 -> M2 -> E1B -> E2/E4 -> E5/E7 -> T1 -> D2.
    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
2026-08-28 Requirements: 58-requirement tree, plus the in-band comms link
    Decomposes the vision into 13 SYS requirements and 34 discipline requirements
    across electrical, mechanical and firmware. StrictDoc builds clean and
    req-trace reports no orphans and no undecomposed levels.
    SYS-004 is the budget parent: 90% end-to-end at 3 kW is 300 W of loss, divided
    as 25 W TX inverter, 120 W coil pair, 40 W RX rectifier, 100 W vehicle-side
    DAB and 15 W auxiliary, summing exactly to the parent. Each child's RATIONALE
    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
2026-08-28 Architecture: block diagram and power budget across all three boards
    29 blocks, 8 rails, 19 buses. block-diagram --check passes.
    The gate did its job: the first pass came out over budget on two transmitter
    rails, which is the concrete form of the v1 white paper's confusion between
    "TPSM540" and "TPSM560". Neither name is a real part, and the family it means
    tops out at 600 mA, which the transmitter aux tree exceeds. Raised to the
    1.5 A TPSM5601R5.
    A second v1 problem fell out of drawing the tree at all: the white paper runs
    its auxiliary rails from that same TPSM part directly off the 400 V bus, but
    every member of the family is rated 60 V maximum input. A 700 V-class offline
    flyback stage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
    [block-diagram.yaml]
2026-08-28 Plan: mark R1 done and E1B in progress, re-render
    E1B stays in progress rather than done: the diagram and the tree shape are
    agreed but the currents are estimates until E1 settles the parts and M2 the
    magnetics.
    Ready to start now: M1 (coil bench characterisation) and E1 (power
    architecture and part selection).
    Claude-Session: https://claude.ai/code/session_018xNdiSQv3JdagdWVUHe6u6
2026-08-28 Charge-rate policy, bidirectional converter, and a plan with no lab in it
    Three inputs from the human land in the requirements and the plan.
    CHARGE RATE (SYS-014, FW-011). Normal 0.3-0.5C, ceiling 1.0C, against a
    CONFIGURED pack capacity rather than a fixed current -- a fixed limit stops
    protecting the pack the moment the capacity changes, which is the one thing
    the pack is expected to do. sim/link-budget/charge_policy.py works both
    directions: today's 1.58 kWh pack accepts 1584 W at its 1.0C ceiling, so the
    usable ceiling is 53% of the charger's rating and normal charging is
    475-792 W. Inverting it, 3 kW is a normal-band charge for a pack of 6 kWh at
    0.5C to 10 kWh at 0.3C -- and the white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
    [plan.yaml]
2026-08-28 M1: coil inductance, coupling and Q predicted by analysis
    Chunk M1, reworked from bench characterisation to analysis. Three scripts under
    sim/coil/, each cross-checked rather than trusted:
    coil_model.py filament summation with Maxwell's elliptic-integral
    mutual term, cross-checked against the Mohan
    current-sheet fit -- they agree to 2.6-4.2%
    coil_coupling.py Neumann double integral for the misaligned case,
    validated against the analytic coaxial result to 0.14%
    before being used off-axis
    coil_resistance.py DC resistance from geometry, Kuhn-Ibrahim for the etched
    spira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
2026-08-28 Architecture rev C: symmetric 48 V, two converter instances, TX part settled
    The Leviathan pack is 48 V nominal, the same as the Mako's, so one low-voltage
    specification covers both ends and SYS-015's "one design, two orientations"
    resolves cleanly. The dock instance runs LV->HV to make the 400 V link; the
    vehicle instance runs HV->LV into the pack.
    That symmetry removes a problem rather than adding one. Rev B needed a
    700 V-class offline flyback to make the transmitter's auxiliary rails from the
    400 V bus, because the dock supply was assumed to be 400 V. With a 48 V pack on
    the dock, the transmitter takes 48 V over the dock harness and uses the same
    buck as the vehicle. That stage is gone.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
    [block-diagram.yaml, plan.yaml]
2026-08-28 R2: environmental envelope for open-deck marine service
    SYS-016 and MEC-008 set the ambient the thermal work runs against: -25 to
    +55 degC operating, open-deck enclosure, surface vessel operating worldwide.
    The maximum is not a round number, it is a derivation: IEC 60945 builds its
    exposed-equipment limit from a maximum expected air temperature at sea of
    +32 degC plus a maximum solar gain of +23 degC. The solar term is the larger
    half, which is exactly why an open-deck enclosure and an enclosed space are
    different problems and why the user's answer to that question mattered.
    The consequence is tighter than the number looks. At +55 degC ambient with
    conduction cooling only and MEC-004's 100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
    [plan.yaml]
2026-08-28 README: replace the template placeholder, and keep the review report in-repo
    The README still opened with "# <project name>" and the template's
    getting-started boilerplate. Replaced with what the project actually is, where
    the analysis lives, and how to reproduce every load-bearing number.
    Also archives the published v1 review as
    docs/design/reports/v1-review-2026-08-28.html so the report survives the
    container, not just the artifact URL.
    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
2026-08-29 Correct the coil conclusion, rebuild the concepts, add review gates and Pages
    Four things, all from review feedback.
    CORRECTION — an etched PCB coil meets MEC-001. The previous conclusion, that
    PCB coils could not reach the loss budget and Litz was required, was wrong. It
    tested a SINGLE-LAYER spiral and then generalised to a whole conductor
    technology; parallel layers, the obvious lever, were never modelled.
    sim/coil/coil_rect.py computes the house's 102 x 203 mm rectangle directly --
    Grover's rectangular-loop formula per turn, numerical Neumann integration for
    every turn pair and for the coil-to-coil mutual, so gap, offset and tilt need
    no symmetry assumption. Result: 32 turns of 0.80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
    [plan.yaml]
2026-08-29 Plan: model the vision agreement as its own gate chunk
    plan-render --check caught the bookkeeping error in the previous commit: R1 and
    R2 were done but depended on a V1 that had been reopened. The gate was right and
    the fix is a better model of what actually happened.
    V1's artefacts genuinely exist, so V1 is done. What never happened is the
    AGREEMENT on them, and that is now G1 — its own chunk, in progress, holding the
    review record and the artifact. M2 and E1 depend on G1 rather than on V1,
    because designing against an unagreed vision is precisely what produced two bare
    coil pads when the human wanted to see a product.
    27 chunks, 16 sessions on the critical path.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
    [plan.yaml]
2026-08-29 Gate 1 decisions: deck bracket, belly dock, no actuator, charging-system scope
    Applies the answers from the gate-1 review.
    SCOPE — the vehicle is not ours. The concepts are rebuilt to show the charging
    system only: the deck bracket, both coil pads in their housings, the gap, and
    the converter enclosure. The vehicle appears only as the interface plate its
    pad bolts to. The three concepts now differ on the remaining real decision --
    how the pads locate to each other: cone-vee-flat kinematic, tapered rails, or a
    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
2026-08-29 Gate 1: record the decisions, with coil technology delegated pending its ADR
    Belly dock, no actuator, charging on deck in a locating bracket, scope limited
    to the charging system, 4 x 8 inch pad. Coil technology is delegated to me and
    is deliberately NOT recorded as decided: the evidence that settles it -
    published measured Q for multilayer PCB coils, and how badly ideal 1/N layer
    scaling breaks down - is still being gathered. G1 stays in_progress until
    adr-0001 exists with its citations.
    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
2026-08-29 ADR-0001: keep the PCB coil, transposed multi-track, bracket as heat sink
    The research commissioned to defend the six-layer PCB coil refuted it, and
    found the defect that produced it. coil_rect.py computed
    r_dc = rho*length/(w*t*layers) and then multiplied by the proximity factor,
    which divides the proximity loss by N as well. Proximity resistance depends on
    conductor volume and B squared and NOT on the current a conductor carries
    (Nguyen and Fortin Blanchette, Electronics 2020, 9, 1324, Eq. 2), so parallel
    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
2026-08-29 Close gate 1: PCB kept, sized against the worst corner, sources in the manifest
    Final sizing, against the BINDING condition -- the 14 mm gap with 5 mm offset,
    not the nominal: 24 turns, 0.25 mm trace on 0.20 mm space, 4 oz, 16 transposed
    layers. M = 94.6 uH against the 80.9 required, k*Q = 75.0 against 49. Twelve
    layers is the floor at 61.1. A plain parallel stack of the same geometry
    reaches 45.2 and fails.
    The decision survives transposition being only half as effective as intended
    (k*Q = 60.9), which is the margin it actually rests on.
    Two consequences the human should see plainly, both now in the ADR and the gate
    record. Sixteen layers at 4 oz is 64 oz of copper in one board -- a heavy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
    [plan.yaml]
2026-08-31 Update to MakeHardware v0.2.0 and generate the review artefacts
    The installed plugin was v0.1.0 at commit 17c74a2, from a branch that no
    longer exists upstream. Current main is 93ed502, v0.2.0, and the entire update
    is about the gap this session hit repeatedly: it adds skills/hw-review,
    bin/review-gate, bin/review-artifact, a docs/review/ template, and a `review:`
    field in plan.yaml that plan-render --check enforces, so a chunk cannot be
    called done without a committed sign-off.
    It also fixes the block_diagram.py budget defect logged in the friction log:
    child rails are now referred through the voltage ratio, and where a voltage is
    missing it rolls up 1:1 and says so rather than inventing a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
2026-08-31 Open all four milestone reviews and publish the project review page
    Every milestone this project has passed was passed without anyone looking at
    it. review-gate now has all four open with the artefacts committed, the
    github.com links resolving, and two real questions each:
    vision which locating approach, and is a 64 oz heavy-copper board
    acceptable or should Litz be re-opened
    plan is this all the work, is the order right
    requirements are the numbers right, is anything missing
    architecture is a rail missing, is one converter design in two orientations
    the right call
    review-artifact --check reports the page clear -- four phases, every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
    [reviews.yaml]
2026-08-31 Plan: wire chunks to the review ledger, and stop claiming unsigned work is done
    plan-render in v0.2.0 checks two things v0.1.0 did not: that a done chunk's
    declared outputs exist on disk, and that its declared review is signed. Both
    caught real claims that did not hold.
    The outputs check found G1 pointing at docs/design/reviews/gate-1-vision.md,
    which moved to docs/review/ in the last commit. Fixed.
    The review check found more. V1 and R1 were marked done while the reviews they
    rest on had never been sent, let alone answered. Held at in_progress, and the
    dependency check then cascaded honestly to R2 and M1 -- their work is complete
    and reproducible, but it rests on an unsigned vision, and i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
    [plan.yaml]
2026-08-31 Fix the overlapping block diagram, narrow scope to electronics + test rig
    Three problems reported by the customer.
    The architecture diagram was self-overlapping. block-diagram reads hand
    positions back out of the existing .drawio and pins the layout to them with
    no collision test, so when rev C added the seven dock-DAB blocks the
    pre-existing twenty-nine stayed at their rev-B coordinates and eight pairs
    landed on top of each other. block-diagram --check exited 0 on it. A fresh
    layout has zero overlaps. Fourteen block names were also being cut mid-word
    at the renderer's 24-character limit and are shortened in the spec.
    36 blocks and 23 buses do not fit one readable sheet, so each block now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
    [block-diagram.yaml, plan.yaml, reviews.yaml]
2026-08-31 Redraw the architecture as three modular sheets, left to right
    The column grid was the problem, not just the collisions. block-diagram
    assigns columns by a heuristic that put eight of the dock sheet's ten
    blocks in column one, routes buses vertically straight through boxes, and
    has no notion of a module, so the dual active bridge was drawn twice
    because the master spec instantiates it twice. None of that is reachable
    from the spec side, so scripts/arch_diagram.py draws the views instead.
    Layout is a stage grid: stages run left to right in the direction power
    flows, rows within a stage are free. Every vertical run happens either in
    a gutter between two stage columns, which is empty by constr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
    [plan.yaml, reviews.yaml]
2026-08-31 Put every architecture sheet on the review page, and fit them to it
    Two faults, both of which reached the customer.
    The review page's architecture tab was showing one diagram where four had
    been sent for review. review_artifact.py's phase_architecture is hardcoded
    to docs/design/block-diagram.svg and never reads the review's artefact
    list - review-gate --artifact and the page's figures are two unrelated
    mechanisms. Replaced with a configured phase in docs/review/artifact.yaml
    carrying all four figures, the rail budget as a CSV table, and links to
    the sources. `hide` also suppresses a configured phase of the same id as
    the standard one, and a review binds to a phase by id, so the review move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
    [power-budget.csv]
2026-08-31 Simulate the resonant link and solve for the DAB transformer
    Two ngspice decks, every point cross-checked against closed form.
    The white paper supports a faithful simulation of the resonant link - it
    gives measured coil values on page 6 and the rectifier bulk capacitance on
    page 5. It does NOT support one of the DAB: page 8 names every
    semiconductor and none of the three parameters that set a DAB's power
    transfer, so sim/dab runs the inverse and solves for the transformer
    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
2026-08-31 Put the simulation on the review page
    The review page is the only view the customer has, so the decks and their
    findings need to be on it, not just in the repo. Adds a Simulation tab
    carrying sim-findings.md and both generated result tables, and opens the
    review with the two findings that need a decision: F16, that 3 kW puts the
    rectifier at 471-622 V rather than the 400 V the HVDC rail assumes and
    swings 32% across the docking envelope, and F17, that the vehicle DAB's
    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
2026-08-31 Add a KiCad DAB schematic that simulates, and correct the M target
    Answers two questions from the customer.
    The M = 80.9 uH figure is about the WIRELESS TX-to-RX link, not the DAB.
    But the question exposed a real muddle: that number comes from the
    both-ends-actively-switched formula P = V1*V2/(w*M), while sim/link/link.cir
    models the passive diode rectifier the block diagram actually specifies,
    for which P = V1^2*R_ac/(w*M)^2. The two describe different receivers, and
    F16's 471-622 V output is the symptom. Recorded as F18. It sharpens the
    F16 decision rather than replacing it: active rectification restores
    M = 80.9 uH as the target and regulates the output to 400 V at once.
    Following that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
    [dab-sim.kicad_pcb, dab-sim.kicad_sch]
2026-08-31 Redraw the DAB schematic with wires instead of net labels
    A schematic wired only by net names is correct for the netlister and
    useless to a human - you cannot trace the bridge by eye. Rebuilt so that
    every power connection is a drawn line: both DC rails, the four bridge
    legs, the body diodes, the transformer between the low-voltage midpoints
    and the 56 uH in the secondary path. Only the four gate nets stay as
    labels, which is normal practice; drawing them would put eight wires
    across the sheet for nothing. The power nets now carry names as well as
    wires, so the exported netlist reads VLV_48V / LA / LB / HA / HB /
    VHV_400V rather than Net-_D1-A_.
    The rails are drawn above and below the switc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
    [dab-sim.kicad_sch]
2026-08-31 Make sim/kicad runnable on someone else's machine
    The folder had the schematic but not the instructions or a reproducible
    path. Adds run.sh, which exports the netlist from the schematic with
    kicad-cli, swaps the sheet's .tran for a .control block that measures,
    runs ngspice and prints input power, output power, efficiency and tank
    current against the closed-form value. It degrades to --no-plot cleanly
    when matplotlib is absent and takes PYTHON= to find one that has it.
    The README now covers what to install per platform (ngspice ships with
    KiCad on Windows and macOS; Linux needs libngspice0), how to open and
    run, which nets to probe and what each shows, and how to move the
    operating point by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
2026-08-31 Correct the simulator instructions: menu location and the settings prompt
    Two things I got wrong, both reported from an actual KiCad session.
    The Simulator is in the Schematic Editor, not the Project Manager - there
    is no Inspect menu in the project view, so "open the project then Inspect
    > Simulator" sent the reader nowhere. The README now says to open the
    schematic first.
    Run prompts for the simulation settings even though .tran is on the
    sheet. KiCad treats a text item as THE simulation command only when its
    first line starts with a dot, and this sheet's directive block starts with
    K1. Both lines still reach the netlist - the coupling and the analysis are
    genuinely exported, which is wh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
2026-08-31 Fix the transformer coupling for KiCad's GUI simulator
    Reported from a real run: the GUI dies with "unimplemented dot command
    '.k1'". K is a DEVICE line in SPICE, not a dot command, and KiCad's GUI
    netlister prepends a '.' to any schematic directive that does not already
    start with one - so "K1 L1 L2 0.9999" arrives as ".k1 l1 l2 0.9999" and
    the circuit does not parse. kicad-cli does not do this, which is why
    run.sh produced correct numbers while the GUI could not run at all. Both
    behaviours reproduced here.
    Adds coupling.cir holding the K statement, to be pulled in from the sheet
    with ".include coupling.cir" - which starts with a dot, so neither
    netlister touches it and ngspice reads a pro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
2026-08-31 Document the include path forms that actually resolve in KiCad's simulator
    A relative .include does not work in the GUI: KiCad drives ngspice as a
    shared library and hands it the netlist in memory, so there is no netlist
    file for a relative path to resolve against and the DLL's working
    directory is not the project folder - "Could not find include file
    coupling.cir".
    Two forms do work, both now documented: "${KIPRJMOD}/coupling.cir", which
    stays portable, and a literal absolute path as the fallback. Both must be
    QUOTED and are safest with forward slashes - verified here that an
    unquoted include fails on a path through a directory named "Wireless
    Charging Sim" and succeeds quoted.
    run.sh is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
2026-09-01 Replace the K directive with a transformer subcircuit KiCad resolves itself
    Three failures in a row all had the same root: mutual coupling reaching
    ngspice through schematic text. K is a DEVICE line, not a dot command, and
    the GUI netlister prepends a dot to any directive lacking one, so a bare K
    arrives as ".k1" and the circuit will not parse. A relative .include fails
    too - KiCad drives ngspice as a shared library and hands it the netlist in
    memory, leaving no file for a relative path to resolve against.
    The windings and their coupling now live in xfmr.lib as a subcircuit,
    attached to a real Device:Transformer_1P_1S symbol by Sim.Library =
    ${KIPRJMOD}/xfmr.lib. Verified that KiCad resolve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
    [dab-sim.kicad_sch]
2026-09-01 Give every diode real parameters - ideal diodes were aborting the run
    Reported: the circuit now parses and runs, but the transient aborts with
    "Timestep too small ... trouble with __d4-instance d4" at 9.9 us.
    Cause is mine. When I deleted and re-placed the diodes to fix their
    rotation, the re-place wiped their Sim.Params and I only restored
    Sim.Device and Sim.Pins. All eight were therefore running on ngspice
    defaults - IS=1e-14, RS=0, CJO=0 - a perfectly ideal diode with no series
    resistance and no junction capacitance, which in a hard-switching bridge
    is a reliable way to stall the timestep. Verified from the exported
    netlist: eight ".model __Dn D" lines with no parameters at all.
    All eig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
    [dab-sim.kicad_sch]

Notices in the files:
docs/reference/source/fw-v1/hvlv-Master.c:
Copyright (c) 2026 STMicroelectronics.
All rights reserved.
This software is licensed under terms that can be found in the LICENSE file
